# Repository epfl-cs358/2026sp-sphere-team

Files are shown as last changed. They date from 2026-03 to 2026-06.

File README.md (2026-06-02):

#  Sphere Robot

WhatsApp Image 2026-05-27 at 22 32 17

https://github.com/user-attachments/assets/e3d25818-d407-4145-80b4-8669d89c7ae2

A spherical robot inspired by BB-8. CS-358 final project, EPFL.

---

## Project Overview

It is a spherical robot inspired by BB-8 from Star Wars. A 3D-printed shell rolls on the ground, driven from the inside by a small chassis with three omnidirectional wheels. On top of the sphere, a separate "head" is held only by magnets, so it can rotate freely as the sphere moves. The head carries a camera.

The robot:

- Rolls in any direction using 3 omni wheels at 120° spacing, tilted inward at 30° against the inside of the sphere.
- Is driven over Wi-Fi from a browser dashboard.
- Streams live video from the head camera (planned — head firmware is in progress).
- Self-stabilizes with a 9-DOF IMU and a 100 Hz control loop.
- Can be reflashed over Wi-Fi (OTA), so the sphere doesn't have to be opened.

---

## Table of Contents

- [Bill of Materials](#bill-of-materials)
- [Build the Robot](#build-the-robot)
- [Algorithms](#algorithms)
- [Control Architecture](#control-architecture)
- [Communication Protocol](#communication-protocol)
- [Web App](#web-app)
- [Code — Repository Structure](#code--repository-structure)
- [Quick Start](#quick-start)
- [Make Commands](#make-commands)
- [Body Firmware (ESP32 C++)](#body-firmware-esp32-c)
- [Head Firmware](#head-firmware)
- [Webapp (Next.js — port 3003)](#webapp-nextjs--port-3003)
- [Stream Client + Relay (ports 3004/3005)](#stream-client-nextjs--port-3004--relay-port-3005)
- [System Requirements](#system-requirements)
- [WiFi Configuration](#wifi-configuration)

---

## Bill of Materials

### Electronic Components

| Component | Part | Notes | Link |
|---|---|---|---|
| Microcontroller (body) | ESP32 Wemos D1 R32 / UNO32 | Runs the control loop and the WebSocket server | Course provided |
| Camera (head) | XIAO Vision AI Camera (Seeed Studio) | Streams video from the head | [Digikey](https://www.digikey.ch/de/products/detail/seeed-technology-co-ltd/102010635/26553888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) |
| Motors (×3) | DFRobot FIT0186 | 12 V DC gear motors with encoders, one per omni wheel | [Bastel Garage](https://www.bastelgarage.ch/moteur-a-engrenages-dc-12v-251rpm-18kg-cm-avec-encodeur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) |
| Motor drivers (×3) | L298N H-bridge modules | One channel per motor | Course provided |
| IMU | Adafruit BNO055 | 9-DOF with built-in sensor fusion, I²C address 0x28 | [Bastel Garage](https://www.bastelgarage.ch/bno055-intelligent-9-axis-sensor) |
| Battery | LiPo | 5000mAh / 3S = 11V | Course provided |
| BMS | 3S 60A | Protects the LiPo | Course provided |
| Buck converter | LM2596 (or equivalent) | 12 V → 5 V for the ESP32 | Course provided |
| Servo | SG90 | Changes the angle of the camera | Course provided |
| Head Battery | Li-Ion Battery 3.7V 3200mA NCR18650B 18650 with Flat Top | Battery for servo and camera | [Bastel Garage](https://www.bastelgarage.ch/li-ion-battery-3-7v-3200ma-ncr18650b-18650-with-flat-top) |
| Head Battery shield | 1x18650 Lithium Battery Shield 5V 3A / 3V 1A | TO connect the head battery  | [Bastel Garage](https://www.bastelgarage.ch/1x18650-lithium-battery-shield-5v-3a-3v-1a) |

### Mechanical Parts (Body)

| Part | Material | Notes | File |
|---|---|---| --- |
| Omni wheels (×3), ~9.25 cm diameter | PETG/TPU  (3D printed) | | [Omniwheel](./README_files/Omniwheel) |
| Metal sticks (x15), 3mmx35mm | Steel (any metal can be used) |  Metals parts used to hold the omni wheels assembly |  |
| Motor Holder | PETG (3D printed) | One peice that holds the 3 motors at 120°, tilted inward by 30° | [Motor Holder](./README_files/Body/Motor%20holder.step) |
| Internal plates | MDF (laser-cut) | Structure for the electronical components | [Bottom](./README_files/Body/Internal%20Plate%20(Bottom).step) [Side for LiPo](./README_files/Body/Internal%20Plate%20(Side%20for%20LiPo).step) [Side](./README_files/Body/Internal%20Plate%20(Side).step) [Top](./README_files/Body/internal%20Plate%20(Top).step) |
| BMS Box | PETG (3D printed)  |  | [BMS Box (Cage)](./README_files/Body/BMS%20Box%20(Cage).step) [BMS Box (Plate)](./README_files/Body/BMS%20Box%20(Plate).step) |
| Tube Holder | PETG (3D printed) | Holds the tube for the magnets | [Pipe Holder](./README_files/Body/Pipe%20Holder.step) |
| 2 metal pipes (1.5mm(external diamateter) x 60mm & 2.5mm(external diamateter) x 200mm)| Aluminium (any metal can be used) | Tubes to hold and adjust the magnet holder and upper ball bearing |  |
| Hose clamp | PETG (3D printed) | Made to hold the bard in the body and make the magnets height adjustable | [Hose Clamp](./README_files/Body/Hose%20Clamp.step) |
| Magnet Holder | PETG (3D printed) | Holds all 3 magnets at the correct place | [Magnet Holder](./README_files/Body/Magnet%20Holder.step) |
| Magnets (x6) | Neodymium | (Ø 20 mm, height 5 mm N42) ; hold the head onto the sphere | [Supermagnete](https://www.supermagnete.ch/fre/aimants-disques-neodyme/disque-magnetique-20mm-5mm_S-20-05-N)|
| Sphere shell, 35 cm diameter | PETG (3D printed) | Two hemispheres, joined with magnets and tape | [Hemisphere](./README_files/Body/Sphere%20Shell%20(Hemisphere).step) [Rail](./README_files/Body/Sphere%20Shell%20(Rail).step) |

### Mechanical Parts (Head)
| Part | Material | Notes | File |
|---|---|---| --- |
| Head-to-sphere contact | Metal ball-bearings in 3D-printed cages | Low-friction contact between head and sphere | [Head-to-Sphere-folder](./README_files/Head-to-sphere%20contact) |
| Balls (14mm diameter) | Stainless Steel | Balls used in the heads ball bearing | [123Roulement](https://www.123roulement.ch/accessoire/bille-aiguille/bille/ba-14-aisi304) |
| Head shell | PETG (3D printed) | Holds the camera and magnets | [Head Shell](./README_files/Head/Head%20Shell.step) |
| Servo Holder | PETG (3D printed) | Holds the servo for the camera | [Servo Holder](./README_files/Head/Servo_Holder.step) |
| Camera Holder | PETG (3D printed) |  | [Camera Holder](./README_files/Head/Camera_Holder.step) |
---
---

## Build the Robot

### Sphere Shell

The sphere is what the wheels push against, so it needs to be round, rigid, and smooth on the inside. Inner radius is ~17.5 cm (35 cm diameter), matching the `ROBOT_RADIUS` constant in the firmware.

1. 3D print the two hemispheres (top and bottom) in PETG on a large-format printer (e.g. Prusa XL).
2. Set the slicer with the PETG optimal profile for your printer, using:
- Perimeters: 4
- Infill: 15%
- Supports: Organic supports, enabled for overhangs above 60°
3. Sand the inside of each hemisphere until it feels smooth. This is what gives the wheels good grip.
4. Add and glue the 27 rails onto one hemisphere.
5. Only join the two hemispheres at the very end, once the chassis is in place inside.



### Internal Chassis

The chassis holds the three motors at 120° spacing, each tilted inward at 30° from vertical so the wheels press against the inside of the sphere.

1. 3D print the [Motor Holder](./README_files/Body/Motor%20holder.step)
2. Lazer cut the internal plates ( [Bottom](./README_files/Body/Internal%20Plate%20(Bottom).step) [Side for LiPo](./README_files/Body/Internal%20Plate%20(Side%20for%20LiPo).step) [Side](./README_files/Body/Internal%20Plate%20(Side).step) [Top](./README_files/Body/internal%20Plate%20(Top).step) )
3. Test-fit the three motors first — don't glue or screw anything down until they fit cleanly.
4. Glue the bottom plate to the motor holder.
5. Gule the walls of the plates and screw the top plate on the walls.
6. Screw the [Pipe Holder](./README_files/Body/Pipe%20Holder.step) at the center of the plate and glue the 20mm tube inside.
7. Add the [Hose Clamp](./README_files/Body/Hose%20Clamp.step) and the 15mm tube on top.
8. Make sure the Hose clamp is well fitted in the lower tube (it should be pressed down).
9. Place the [Magnet Holder](./README_files/Body/Magnet%20Holder.step) on the upper tube.
10. Glue a ball transfer unit to the top of the tube.
11. Add the magnets to the magnet holder (make sur they all point in the same direction)
12. You will be able to adjuste height of the magnet holder and ball transfer unit once you have the complete sphere.
13. 3D print and screw on the upper plate the [BMS Box (Cage)](./README_files/Body/BMS%20Box%20(Cage).step) and [BMS Box (Plate)](./README_files/Body/BMS%20Box%20(Plate).step).
14. Screw every body electronical component onto it (there are two drivers on the bottom plate and one on top).
15. Mount the motors.
16. Mount the IMU as far as possible from the head magnets, and as low as possible in the chassis. A low center of mass keeps the robot stable.
17. Do the wiring (follow the electronical diagram)
   




### Motors and Wheels

1. 3D Print every file in the [Omniwheel](./README_files/Omniwheel) folder. Note that the material that should be used is in the file name.
2. Follow the following steps : https://github.com/epfl-cs358/2026sp-sphere-team/issues/80
4. Check the rolling direction. Choose one motor to be the front of your robot :  Motor 0 is at the front, motor 1 back-right, motor 2 back-left. If a motor spins the wrong way, swap fwd/rev in `body-firmware/src/config/pins.h` rather than rewiring.

### Electronics Assembly

**Electronics schematics**



**Motor drivers (L298N)**

| Motor | ESP32 GPIO (forward) | ESP32 GPIO (reverse) |
|---|---|---|
| 0 (front) | 14 | 27 |
| 1 (back-right) | 16 | 17 |
| 2 (back-left) | 25 | 26 |

Jumper EN HIGH on all three L298N boards. Connect L298N GND to ESP32 GND.

**Encoders**

| Motor | Encoder A | Encoder B |
|---|---|---|
| 0 | 34 | 35 |
| 1 | 2 | 4 |
| 2 | 36 | 39 |

**IMU (BNO055)**

| BNO055 | ESP32 |
|---|---|
| VIN | 3.3 V |
| GND | GND |
| SDA | 21 |
| SCL | 22 |

I²C address: 0x28.

**Power wiring**

```
LiPo ──┬── BMS ──┬── 12 V ──── L298N supply (×3)
       │         │
       │         └── LM2596 ── 5 V ── ESP32
       │                            └── BNO055 + encoders (via ESP32 3.3 V)
       └── status LED
```


> Add bulk capacitance (≥ 1000 µF + 0.1 µF ceramic) on the 12 V rail near each L298N. Without it, the motors will brown out the ESP32 every time you accelerate.

### Head and Camera

The head houses the XIAO Vision AI Camera and its own battery. It joins the same Wi-Fi as the body but streams video separately.

1. 3D print the [Head Shell](./README_files/Head/Head%20Shell.step), the [Servo Holder](./README_files/Head/Servo_Holder.step) and the [Camera Holder](./README_files/Head/Camera_Holder.step).
2. Screw the servo on the Servo holder.
3. Attach the camera to the camera holder.
4. Place the camera holder on the Servo.
5. Wire the Servo to the camera chip (follow the electronics head schematics).
6. Add the entenna to the exterior face of the head and connect it to the camera chip.
7. Screw the servo holder in the head.
8. Screw the head battery shield in the head.



   
9. Print every component in the [Head-to-Sphere-folder](./README_files/Head-to-sphere%20contact).
10. Screw the Ball Transfer Unit (Support) on the Head-to-sphere contact.
11. Add the ball and tube on top.
12. Place the magnets. Watch out that they should all point to the opposite direction from the body magnets.
13. Screw the Head-to-sphere contact to the sphere once everything works properly.



---

## Algorithms

### Omni-Wheel Inverse Kinematics

Given a desired body velocity (vx, vy, ω), we compute each wheel's target speed using the geometry of a 120°-spaced, inward-tilted omni layout.

For a wheel at angle θᵢ from the front:

```
ωᵢ = (1 / (r · cos α)) · [ −sin(θᵢ)·vx − cos(θᵢ)·vy − R·ω ]
```

where `r` is the wheel radius, `R` is the distance from the chassis center to the wheel contact, and `α` is the wheel tilt.

Robot constants (from `RobotConstants.h`):

| Parameter | Value |
|---|---|
| Wheel radius `r` | 0.046225 m (9.245 cm diameter) |
| Robot radius `R` | 0.1745 m (center to wheel contact) |
| Tilt angle `α` | 30° |
| Max RPM | 251 (per-wheel saturation) |

For our layout (θ₀ = 0°, θ₁ = 120°, θ₂ = 240°):

```
           1            ┌  0     −1     −R  ┐   ┌ vx ┐
[ωᵢ] = ───────────  ·   │ −√3/2   1/2  −R   │ · │ vy │
       r · cos(α)       └  √3/2   1/2  −R   ┘   └  ω ┘
```

Quick sanity checks:
- Pure forward → motor 0 doesn't spin, motors 1 and 2 spin opposite ways. ✓
- Pure rotation → all three spin in the same direction at the same speed. ✓
- Flat layout (α = 0) → equations match the standard 3-omni textbook case. ✓

Full derivation: `code/body-firmware/docs/omni-kinematics-derivation.md`

### Per-Wheel PID

Each motor has its own PID loop tracking the target speed from the kinematics.

| Parameter | Value |
|---|---|
| Input | Target RPM from kinematics |
| Feedback | Actual RPM from encoder |
| Output | PWM duty cycle (−1.0 to +1.0) |
| Kp / Ki / Kd | 0.005 / 0.002 / 0.0005 |
| Integrator clamp | ±5.0 |
| Loop rate | 100 Hz |

Code: `code/body-firmware/src/control/PID.h`

### Tilt-Limit Controller

The motors are powerful enough that on hard acceleration the chassis can climb the inside of the sphere and flip over. To prevent this, a controller watches the IMU:

| State | Condition | Action |
|---|---|---|
| Active | tilt < 15° | Normal driving |
| Recovery | tilt 15–20° | Coast motors, ignore joystick, wait for gravity. Re-engages once tilt drops ~3° |
| Stopped | tilt > 20° | Brake all motors, reset PIDs |
| Hard cap | tilt > 30° | Brake immediately, regardless of mode |

> **Status**: designed (see `controller-discussion.md`) but not yet integrated. The current shipping controller is a simple pass-through (`PassthroughDrivetrainController`), which is fine on flat ground with a careful operator.

---

## Control Architecture

### How the Two ESP32 Cores Split the Work

- **Core 0** runs the WebSocket server. It receives `vx,vy,omega` text frames from the laptop and drops the latest one into a one-slot mailbox (old commands are overwritten, never queued).
- **Core 1** runs the 100 Hz control loop. It reads the latest command, reads the IMU, runs the kinematics and the PIDs, and updates the motors.

```
WebSocket frame → mailbox → control loop (100 Hz) → kinematics → 3 × PID → 3 × motor
```

### Safety Properties

- **Stale commands stop the robot.** If no fresh command arrives within 200 ms, motors ramp smoothly to zero. No jerk, no runaway.
- **Watchdog reboot.** If the control loop ever hangs, the ESP32 resets itself within 1 second.
- **Wi-Fi watchdog.** If Wi-Fi has been disconnected for more than 30 s, the ESP32 reboots to reconnect cleanly.
- **Safe OTA.** Flashing over Wi-Fi first stops accepting commands, so the ramp-to-zero takes effect before the firmware is overwritten.
- **Latest command wins.** A joystick command from a second ago is worse than no command, so we never queue — we always use the most recent frame.

---

## Communication Protocol

The laptop talks to the body ESP32 over WebSocket on the local Wi-Fi.

- The ESP32 is the server, listening on port 80.
- The webapp is the client.

### Command Format

Plain text, comma-separated:

```
"vx,vy,omega"
```

| Field | Unit | Meaning |
|---|---|---|
| `vx` | m/s | Forward (positive = forward) |
| `vy` | m/s | Strafe (positive = left) |
| `omega` | rad/s | Yaw rate (positive = counterclockwise from above) |

Extra fields at the end are ignored — that's how we'll add new fields later (e.g. `head_tilt`) without breaking older clients.

### Video Stream

The head camera streams video to a small relay server (`code/stream-client/relay.ts`) running on the laptop. The webapp subscribes to the relay to display the feed.

- Camera → `ws://<laptop-ip>:3005/?role=producer`
- Browser → `ws://<laptop-ip>:3005/`

The relay fans out every frame from the camera to every viewer.

---

## Web App

Capture d’écran 2026-05-28 à 00 06 26
Capture d’écran 2026-05-28 à 00 06 46
Capture d’écran 2026-05-28 à 00 06 36

What you can do from the dashboard:

- **Live camera feed** — real-time video from the head.
- **Camera status** — online / offline / reconnecting.
- **Manual control** — joystick or keyboard input.
- **Emergency stop** — immediately sends `0,0,0` and locks input until you resume.
- **Telemetry** — IMU pose, battery voltage, loop rate.

The webapp is a Next.js app on port 3003. The video relay is a small Node server on port 3005. The video viewer is another Next.js app on port 3004.

Before running it, set your Wi-Fi credentials in `code/body-firmware/src/config/wifi_credentials.h`.

---

## Code — Repository Structure

```
code/
├── body-firmware/          # ESP32 C++ firmware for the body (motors, IMU, teleop)
│   ├── src/
│   │   ├── config/         # Pin definitions, WiFi credentials, debug macros
│   │   ├── control/        # Custom PID controller
│   │   ├── drivetrain/     # Omni kinematics, OmniDrivetrain, RobotConstants
│   │   │   └── controller/ # PassthroughDrivetrainController
│   │   ├── imu/            # BNO055 driver (orientation, gyro, calibration)
│   │   ├── input/          # WebSocketCommandProducer, CommandFrameParser
│   │   ├── motor/          # L298N, FIT0186Motor drivers, encoders
│   │   │   ├── constants/  # FIT0186-specific motor constants
│   │   │   └── driver/     # L298NDriver, BTS7960Driver
│   │   └── util/           # Shared types (Vec3, Quat, Euler, MovingAverage…)
│   │       └── sync/       # CommandLatch (thread-safe command queue)
│   ├── test/               # PlatformIO unit tests (native + hardware)
│   │   ├── test_omni_kinematics/
│   │   ├── test_omni_drivetrain/
│   │   ├── test_pid/
│   │   ├── test_command_latch/
│   │   ├── test_command_frame_parser/
│   │   ├── test_bno055_imu/
│   │   ├── test_fit0186_motor/
│   │   ├── test_l298n_driver/
│   │   ├── test_passthrough_controller/
│   │   ├── test_moving_average/
│   │   └── stubs/          # Arduino stubs for native tests
│   ├── platformio.ini
│   └── LIBRARIES.md
├── head-firmware/          # ESP32 firmware for the head (camera/streaming)
│   └── src/config/
├── webapp/                 # Next.js control interface (port 3003)
│   └── src/
│       ├── app/            # Next.js pages (home, /video)
│       ├── components/     # React components (video-stream.tsx)
│       └── lib/video/      # VideoSource abstraction
├── stream-client/          # Next.js streaming client (port 3004)
│   ├── src/app/
│   └── relay.ts            # WebSocket relay server (port 3005)
├── Makefile                # Unified commands for the whole monorepo
├── package.json
└── pnpm-workspace.yaml
```

---

## Quick Start

Before starting up the robot, read the [Safety_Procedures.pdf](https://github.com/user-attachments/files/28337480/Safety_Procedures.pdf)

```bash
make setup   # Install all dependencies
make dev     # Start all services
```

Once running:
- Webapp control interface: [Webapp](http://localhost:3003)
- Stream client: [link](http://localhost:3004) 
- WebSerial: [link](http://bb8-robot.local:81/webserial)

---

## Make Commands

### Development

| Command | Description |
|---|---|
| `make dev` | Start all services (webapp + stream + relay) |
| `make dev-webapp` | Webapp only (port 3003) |
| `make dev-stream` | Stream client only (port 3004) |
| `make dev-relay` | Relay server only (port 3005) |
| `make dev-stop` | Stop all dev servers (ports 3003–3005) |

### Testing

| Command | Description |
|---|---|
| `make test` | Run all tests |
| `make test-firmware` | Native PlatformIO tests (no hardware required) |
| `make test-firmware-head` | PlatformIO tests on hardware |
| `make test-webapp` | Webapp Vitest suite |
| `make test-stream` | Stream client Vitest suite |

### Build & Flash

| Command | Description |
|---|---|
| `make build` | Build entire project |
| `make build-webapp` | Build the webapp |
| `make build-stream` | Build the stream client |
| `make build-firmware` | Compile firmware (no upload) |
| `make flash` | Compile and flash firmware to the robot |
| `make monitor` | Serial monitor (115200 baud) |

### Code Quality

| Command | Description |
|---|---|
| `make lint` | ESLint on both web projects |
| `make typecheck` | TypeScript type checking |

### Setup

| Command | Description |
|---|---|
| `make setup` | Full setup (prerequisites + web + firmware) |
| `make setup-prereqs` | Check/install system dependencies |
| `make setup-web` | Install pnpm dependencies |
| `make setup-firmware` | Install PlatformIO + firmware libraries |
| `make clean` | Remove all build artifacts |

---

## Body Firmware (ESP32 C++)

### Teleop Pipeline Architecture

```
WebSocket client ──text frame──▶ WebSocketCommandProducer (Core 0)
                                          │
                                          ▼
                                  CommandLatch (latest-wins)
                                          │
                                          ▼
                              controlTask @ 100 Hz (Core 1)
                                          │
                                          ▼
                          PassthroughDrivetrainController
                                          │
                                          ▼
                                   OmniDrivetrain
                                  (3× FIT0186Motor + PID)
```

Commands are received over WebSocket on Core 0, stored in a `CommandLatch` (latest-wins, thread-safe), and consumed by the control task running at 100 Hz on Core 1. This dual-core split prevents WebSocket handling from interfering with motor control timing.

### Command Format

Commands are sent as plain text over WebSocket:

```
"vx,vy,omega"
```

| Field | Unit | Description |
|---|---|---|
| `vx` | m/s | Forward velocity |
| `vy` | m/s | Lateral (left) velocity |
| `omega` | rad/s | Rotation rate |

Frame convention: X-forward, Y-left, Z-up (consistent with BNO055 in NDOF mode).

Example: `"0.5,0.0,0.3"` moves the robot forward at 0.5 m/s while rotating at 0.3 rad/s.

### Safety Features

- **Stale command ramp-to-zero**: if no command is received within 200 ms, motors ramp down to zero.
- **Task watchdog**: 1-second timeout on both the control task and WebSocket task.
- **WiFi auto-reboot**: if the robot has been offline for 30 seconds, it automatically reboots.
- **No authentication**: WebSocket runs on `ws://` port 80 — intended for use on a trusted local network only.

### 3-Wheel Omni Kinematics

`OmniKinematics` converts a body-frame velocity `(vx, vy, omega)` into target RPM for each of the 3 motors arranged at 120° intervals. If any motor exceeds `maxRPM`, all outputs are normalized proportionally.

| Parameter | Value |
|---|---|
| Wheel radius | 46.225 mm |
| Robot radius | 174.5 mm |
| Tilt angle | 30° |
| Max RPM | 251 RPM |
| Control period | 10 ms (100 Hz) |
| Stale window | 200 ms |

### PID Controller

Custom PID with:
- **Anti-windup** via integral clamping
- **Derivative on measurement** (not on error) to avoid setpoint-change spikes
- **Configurable deadband**
- Output range: `[-1.0, 1.0]`

Current parameters: `Kp=0.005`, `Ki=0.002`, `Kd=0.0005`

### IMU — BNO055

- Mode: NDOF (9-DOF sensor fusion)
- Outputs: orientation quaternion, Euler angles, gyroscope, linear acceleration, gravity vector, calibration status
- Calibration offsets are saved to and restored from NVS flash (`Preferences`)

### Pin Assignment

| Signal | ESP32 Pin |
|---|---|
| Motor 0 FWD | 14 |
| Motor 0 REV | 27 |
| Motor 1 FWD | 16 |
| Motor 1 REV | 17 |
| Motor 2 FWD | 25 |
| Motor 2 REV | 26 |
| Encoder 0 A/B | 34 / 35 |
| Encoder 1 A/B | 2 / 4 |
| Encoder 2 A/B | 36 / 39 |
| IMU SDA | 21 |
| IMU SCL | 22 |

### PlatformIO Environments

| Environment | Purpose |
|---|---|
| `robot` | USB flash — full teleop firmware |
| `robot_ota` | OTA flash over WiFi (ArduinoOTA) |
| `drivetrain_test` | Drivetrain test firmware with RPM display |
| `motor_test` | Motor + encoder test firmware |
| `wemos_d1_uno32` | Base environment (IMU only) |
| `native` | Unit tests on the host machine |

### OTA Updates

1. Copy `wifi_credentials.example.h` → `wifi_credentials.h` and fill in your SSID, password, and OTA password.
2. Export the OTA password: `export OTA_PASSWORD='your-password'`
3. Flash: `pio run -e robot_ota -t upload`
4. If mDNS resolution fails: `pio run -e robot_ota -t upload --upload-port=<robot-ip>`

> During an OTA update, the `WebSocketCommandProducer` is stopped before flash write — motors stop within the stale window (≤ 200 ms).

### Unit Tests

Tests are located in `body-firmware/test/` and cover:

- Omni kinematics (`test_omni_kinematics`, `test_omni_drivetrain`)
- PID controller (`test_pid`)
- Command synchronization (`test_command_latch`, `test_command_frame_parser`)
- Motor drivers (`test_l298n_driver`, `test_fit0186_motor`, `test_bts7960_driver`)
- Passthrough controller (`test_passthrough_controller`)
- Utilities (`test_moving_average`)
- IMU (`test_bno055_imu`)

Run native tests (no hardware needed):
```bash
pio test -e native
```

Run tests on hardware:
```bash
make test-firmware-head
```

### Firmware Libraries

| Library | Version | Role |
|---|---|---|
| Adafruit BNO055 | 1.6.4 | IMU driver |
| Adafruit Unified Sensor | 1.1.15 | Sensor abstraction layer |
| Adafruit BusIO | 1.17.4 | I2C/SPI communication |
| ESP32Encoder | 0.12.0 | Hardware quadrature encoder reading |
| WebSockets (links2004) | 2.7.3 | WebSocket server for command reception |
| ArduinoOTA | built-in | OTA firmware updates over WiFi |
| FreeRTOS | built-in | Dual-core task scheduling |
| FFF (meekrosoft) | latest | Mocking framework for unit tests |

---

## Head Firmware

The head firmware runs on a second ESP32 and handles camera capture and video streaming. It connects to the stream relay over WebSocket and continuously sends JPEG frames.

Configuration is located in `head-firmware/src/config/`.

---

## Webapp (Next.js — port 3003)

Web control and monitoring interface for BB-8.

**Available pages:**
- `/` — Home page with navigation to modules
- `/video` — Live video feed from the head camera

**Planned modules (in progress):**
- RC Control — real-time keyboard/gamepad teleoperation
- Autonomous mode
- Telemetry dashboard

**Stack:** Next.js 15, TypeScript, Tailwind CSS, Vitest

---

## Stream Client (Next.js — port 3004) + Relay (port 3005)

The streaming client consumes the video feed from the robot's head and makes it available in the webapp through a WebSocket relay server.

### Streaming Architecture

```
Camera (head ESP32)
        │
        ▼
  stream-client (WebSocket producer)
        │  ws://localhost:3005?role=producer
        ▼
     relay.ts (relay server, port 3005)
        │  ws://localhost:3005
        ▼
  webapp video-stream.tsx (consumer)
```

`relay.ts` operates in producer/consumer mode: producers send frames, and the relay broadcasts them to all connected consumers. This decouples the robot's streaming from the number of web clients.

---

## System Requirements

| Dependency | Minimum version | Notes |
|---|---|---|
| Node.js | 18 | Required for webapp and stream client |
| pnpm | latest | Workspace package manager |
| Python | 3.8 | Required for PlatformIO |
| PlatformIO CLI | latest | `pip install platformio` |
| USB access | — | CH340 serial adapter for initial flash |

The development machine and the robot must be on the same local network for teleoperation and OTA updates.

---

## WiFi Configuration

Before the first flash, create the credentials file (gitignored):

```bash
cp code/body-firmware/src/config/wifi_credentials.example.h \
   code/body-firmware/src/config/wifi_credentials.h
```

Then fill in your credentials:

```cpp
#define WIFI_SSID     "your-network"
#define WIFI_PASSWORD "your-password"
#define OTA_PASSWORD  "your-ota-password"
```

> `wifi_credentials.h` is listed in `.gitignore` and will never be committed.

## Team members

| Name | Email |
|---|---|
| Alessandro Lombardini | alessandro.lombardini@epfl.ch |
| Tristan Compain | tristan.compain@epfl.ch |
| Lucas Brunschwick | lucas.brunschwick@epfl.ch |
| Vincent du Fresne | vincent.dufresnevonhohenesche@epfl.ch |
| Alban Thèves | alban.theves@epfl.ch |

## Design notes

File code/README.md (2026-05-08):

# Sphere

Monorepo for the Sphere robotics project — ESP32 firmware, web control interface, and streaming client.

## Quick start

```sh
make setup    # install all dependencies
make dev      # start all services
```

## Make targets

| Target | Description |
|---|---|
| `make dev` | Start all services (webapp + stream + relay) |
| `make dev-webapp` | Webapp only (port 3003) |
| `make dev-stream` | Stream client only (port 3004) |
| `make dev-relay` | Relay server only (port 3005) |
| `make dev-stop` | Stop all dev servers (ports 3003-3005) |
| `make test` | Run all tests |
| `make test-firmware` | PlatformIO native tests |
| `make test-firmware-head` | PlatformIO tests on hardware |
| `make test-webapp` | Webapp vitest |
| `make test-stream` | Stream client vitest |
| `make build` | Build everything |
| `make build-webapp` | Build webapp |
| `make build-stream` | Build stream client |
| `make build-firmware` | Compile firmware (no upload) |
| `make lint` | ESLint both web projects |
| `make typecheck` | TypeScript type checking |
| `make flash` | Compile and upload firmware to board |
| `make monitor` | Serial monitor (115200 baud) |
| `make setup` | Full setup (prereqs + web + firmware) |
| `make setup-prereqs` | Check/install system dependencies |
| `make setup-web` | Install pnpm dependencies |
| `make setup-firmware` | Install PlatformIO + firmware libs |
| `make clean` | Remove build artifacts |

## Body firmware: teleop pipeline

Body firmware ships a teleop pipeline:

```
WebSocket client  ──text frame──▶  WebSocketCommandProducer (Core 0)
                                            │
                                            ▼
                                     CommandLatch  (latest-wins, length-1)
                                            │
                                            ▼
                                  controlTask @ 100 Hz (Core 1)
                                            │
                                            ▼
                                  PassthroughDrivetrainController
                                            │
                                            ▼
                                       OmniDrivetrain
```

- Wire format: text frame `"vx,vy,omega"` (m/s, m/s, rad/s). Trailing fields are ignored for forward-compat.
- Build env: `pio run -e robot` (USB flash) or `pio run -e robot_ota -t upload` (OTA).
- Safety: 200 ms staleness ramp-to-zero, 1 s task watchdog on control + WS tasks, WiFi-offline reboot at 30 s.
- Auth: none — plaintext `ws://` on port 80, intended for trusted-LAN operation only.

## OTA updates

The `[env:robot_ota]` PlatformIO env flashes the device over WiFi via ArduinoOTA. Setup:

1. Set `OTA_PASSWORD` in `body-firmware/src/config/wifi_credentials.h` (gitignored).
2. Export the same password in your shell: `export OTA_PASSWORD='your-password'`.
3. `pio run -e robot_ota -t upload` — uploads to `bb8-robot.local` (mDNS) by default.
4. If `.local` name resolution fails, override with `pio run -e robot_ota -t upload --upload-port=<robot-ip>`.

OTA `onStart` halts the producer task before flash is overwritten so motors ramp to zero via the staleness window.

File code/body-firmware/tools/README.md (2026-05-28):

# BB-8 tuning tools

`tune_pid.py` is a persistent telemetry capture daemon plus a set of LLM-safe inspection commands for tuning the balancing PID. The `tuning-pid-balance` Claude skill (`~/.claude/skills/tuning-pid-balance/SKILL.md`) drives this tool.

## Quick start (foreground)

Install deps once, then run the daemon in the background:

```
pip install -r tools/requirements.txt
nohup python3 tools/tune_pid.py capture --host bb8.local > /tmp/cap.log 2>&1 &
```

Capture writes to `~/.bb8-telemetry/sessions/<id>/` and updates the `~/.bb8-telemetry/current` symlink. Ctrl-C / `kill` flushes cleanly. Re-launching starts a new session.

## Quick start (launchd)

Persistent across reboots and login sessions. Edit `tools/com.bb8.tune-capture.plist` and replace `<USERNAME>` with your macOS username and `<HOST>` with the robot's mDNS name (default `bb8.local`), then:

```
cp tools/com.bb8.tune-capture.plist ~/Library/LaunchAgents/com.bb8.tune-capture.plist
launchctl load   ~/Library/LaunchAgents/com.bb8.tune-capture.plist
launchctl list | grep com.bb8.tune-capture          # verify
```

Logs land in `/tmp/bb8-tune-capture.{out,err}.log`. To stop:

```
launchctl unload ~/Library/LaunchAgents/com.bb8.tune-capture.plist
```

## Install the tuning skill

The skill is already in place at `~/.claude/skills/tuning-pid-balance/SKILL.md`. Invoke from any Claude session via `/tuning-pid-balance`.

## Inspection commands cheat sheet

All subcommands operate on `--session current` by default. Output is bounded JSON — safe to pipe into Claude via Bash.

| Command | Purpose |
|---|---|
| `tune_pid.py sessions` | List sessions with start time, end time, and row count. |
| `tune_pid.py manifest` | Print the active session's manifest (gain + arming history, fault count, seq gaps). |
| `tune_pid.py summary --window 10s` | Default read. Constant-size JSON: per-axis min/max/mean/std, event counts, saturation %, oscillation period if any. |
| `tune_pid.py events --window 30s` | Decoded event rows (`event_flags != 0`) only. Capped at 200 rows. |
| `tune_pid.py slice --around <seq> --max-rows 200 --columns ...` | Narrow window around an event, downsampled, named columns only. |
| `tune_pid.py oscillation --axis pitch --window 10s` | Autocorrelation period + amplitude. Used to derive Tu in Ziegler-Nichols. |
| `tune_pid.py plot --window 30s --out /tmp/last.png` | Six-panel PNG with event markers. Read via Claude's multimodal image input. |

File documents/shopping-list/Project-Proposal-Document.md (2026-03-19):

# Project Proposal — BB8 Robot with Omni Wheels

## 1. High-level project description

## 2. Related projects & resources

Project 1 — 

Project 2 —

...

## 3. User stories

## 4. Product management & afterlif

Follow-up projects for future CS-358 students:

Autonomous navigation (SLAM, obstacle avoidance)
Face tracking via the onboard camera
Embedded voice interface
Gesture recognition for hand-based control

Real, non-EPFL users

Interactive guide
Social companion
Retail environments

Startup opportunity
[Briefly describe the concept: modular robotics platform, SaaS model for behaviors/content, target markets.]

## 5. Shopping List

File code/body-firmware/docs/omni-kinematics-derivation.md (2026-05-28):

# Omni-Wheel Inverse Kinematics Derivation

## Setup

A 3-omniwheel drivetrain inside a spherical shell. Wheels are equally spaced at 120° and tilted inward at angle α from vertical to contact the sphere's inner surface.

### Coordinate Frame (body-frame, right-handed)

- **x**: forward (direction the robot faces)
- **y**: left
- **z**: up

All velocities are in the body frame. Positive omega = counter-clockwise when viewed from above (right-hand rule around z-up).

This matches the BNO055 IMU's default coordinate frame, so no axis remapping is needed.

### Wheel Positions (viewed from above, CCW from body +x)

Angles are measured **counter-clockwise from the body +x axis (forward)** when viewed from above, matching `DrivetrainConfig::wheelAngles` consumed by `OmniKinematics`.

| Motor | Angle θ (CCW from +x) | Physical position |
|---|---|---|
| 0 | 180° | Back |
| 1 | 300° | Front-right |
| 2 |  60° | Front-left |

Each wheel's axis of rotation points toward the center of the robot. The wheel rolls in the direction perpendicular to its axis.

Source of truth for motor index ↔ physical position: `src/main_motor_test.cpp:5-7` and `RobotConstants.h:29`.

### Parameters

| Symbol | Meaning |
|---|---|
| r | Wheel radius (m) |
| R | Robot radius — distance from center to wheel contact point (m) |
| α | Tilt angle from vertical (rad) |
| vx | Forward body velocity (m/s), positive = forward |
| vy | Strafe body velocity (m/s), positive = left |
| ω | Rotation rate (rad/s), positive = CCW from above |

### Tilt correction assumption

The `1/cos(α)` factor assumes the wheel radius `r` already accounts for the sphere contact geometry — i.e., `r` is the effective wheel radius at the contact point, not necessarily the physical wheel radius. This is a valid first-order approximation. If the exact sphere contact geometry differs, `r` should be adjusted accordingly.

## Derivation

### Step 1: Flat-floor 3-omniwheel IK

For a wheel at angle θ_i (measured CCW from body +x when viewed from above), its contact point sits at position `R × (cos θ_i, sin θ_i)`. The wheel's rolling direction is perpendicular to that radial vector, tangent to the circle. We pick the tangent `(-sin θ_i, cos θ_i)` so that positive wheel angular velocity drives the body CCW (matching `+ω = CCW from above`).

The velocity at the wheel contact point has two parts:
1. **Translation**: the robot's linear velocity (vx, vy)
2. **Rotation**: tangential velocity from the body spinning at ω = `R × ω` along the same tangent direction

Projecting the contact-point velocity onto the rolling direction `(-sin θ_i, cos θ_i)`:

```
v_wheel_i = -sin(θ_i) × vx + cos(θ_i) × vy + R × ω
```

The `-sin(θ_i) × vx + cos(θ_i) × vy` term projects the linear velocity onto the rolling direction. The `+R × ω` term adds the rotational contribution: positive ω (CCW) makes all wheels spin in the same positive direction. This matches `OmniKinematics::toWheelRPMs` in `src/drivetrain/OmniKinematics.h:30`.

The wheel angular velocity is:

```
ω_i = v_wheel_i / r
```

### Step 2: Tilt correction

When wheels are tilted at angle α from vertical, the effective radius of contact with the sphere changes. The wheel's force is projected onto the horizontal plane by a factor of cos(α). This means the wheel must spin faster to achieve the same horizontal velocity:

```
ω_i = v_wheel_i / (r × cos(α))
```

At α = 0 (vertical wheels, flat floor), cos(0) = 1 and this reduces to the standard equation. As α → 90° (wheels horizontal), cos(α) → 0 and the required wheel speed → ∞, which is the physical limit where the wheels can no longer drive the sphere.

### Step 3: Full equations

Combining steps 1 and 2:

```
ω_i = (1 / (r × cos(α))) × [-sin(θ_i) × vx + cos(θ_i) × vy + R × ω]
```

### Step 4: Expand per wheel

Using CCW angles θ₀ = 180°, θ₁ = 300°, θ₂ = 60°:

**Motor 0 (back, θ = 180°):**
```
sin(180°) = 0,  cos(180°) = -1

ω₀ = (1 / (r × cos(α))) × [-0 × vx + (-1) × vy + R × ω]
ω₀ = (1 / (r × cos(α))) × [-vy + R × ω]
```

**Motor 1 (front-right, θ = 300°):**
```
sin(300°) = -√3/2 ≈ -0.866,  cos(300°) = 1/2 = 0.5

ω₁ = (1 / (r × cos(α))) × [-(-0.866) × vx + 0.5 × vy + R × ω]
ω₁ = (1 / (r × cos(α))) × [0.866 × vx + 0.5 × vy + R × ω]
```

**Motor 2 (front-left, θ = 60°):**
```
sin(60°) = √3/2 ≈ 0.866,  cos(60°) = 1/2 = 0.5

ω₂ = (1 / (r × cos(α))) × [-0.866 × vx + 0.5 × vy + R × ω]
```

### Step 5: Matrix form

```
┌ ω₀ ┐         1          ┌  0     -1    R ┐   ┌ vx ┐
│ ω₁ │ = ───────────── ×  │  √3/2   1/2  R │ × │ vy │
└ ω₂ ┘   r × cos(α)       └ -√3/2   1/2  R ┘   └ ω  ┘
```

### Step 6: Convert to RPM

```
RPM_i = ω_i × 60 / (2π)
```

## Sanity Checks

### Pure forward (vx > 0, vy = 0, ω = 0)

```
ω₀ = 0                            ← motor 0 (back) is still
ω₁ = +0.866 × vx / (r × cos(α))  ← positive (front-right)
ω₂ = -0.866 × vx / (r × cos(α))  ← negative (front-left)
```

The two front wheels (motors 1, 2) spin at equal magnitude, opposite directions. Forward motion comes from their combined horizontal thrust. Motor 0 (back) contributes nothing — its rolling axis is purely lateral, so it cannot push the shell forward. ✓

### Pure strafe left (vx = 0, vy > 0, ω = 0)

```
ω₀ = -vy / (r × cos(α))          ← negative (back wheel spins one way)
ω₁ = +0.5 × vy / (r × cos(α))   ← positive (front-right)
ω₂ = +0.5 × vy / (r × cos(α))   ← positive (front-left, same as motor 1)
```

Motor 0 (back) takes a single full-magnitude contribution in the negative direction; motors 1 and 2 (front pair) each take half-magnitude in the positive direction. The three contributions sum to net leftward thrust on the shell, matching the `+y = LEFT` REP-103 convention. ✓

### Pure CCW rotation (vx = 0, vy = 0, ω > 0)

```
ω₀ = +R × ω / (r × cos(α))
ω₁ = +R × ω / (r × cos(α))
ω₂ = +R × ω / (r × cos(α))
```

All three motors spin at equal speed in the same positive direction, driving the body CCW from above. ✓

### Tilt angle = 0

All equations reduce to standard flat-floor IK (cos(0) = 1). ✓

## References

- [ROS2 Mobile Robot Kinematics — Omnidirectional Wheels](https://control.ros.org/rolling/doc/ros2_controllers/doc/mobile_robot_kinematics.html)
- [Modern Robotics Ch. 13.2 — Omnidirectional Wheeled Mobile Robots](https://modernrobotics.northwestern.edu/nu-gm-book-resource/13-2-omnidirectional-wheeled-mobile-robots-part-1-of-2/)
- Borisov et al., "Nonholonomic dynamics and control of a spherical robot with an internal omniwheel platform" (2016)
- SpheriDrive: A spherical robot with an innovative 3-wheeled platform (2025)

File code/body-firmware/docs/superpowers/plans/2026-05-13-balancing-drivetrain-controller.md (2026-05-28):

# BalancingDrivetrainController Implementation Plan

**Spec:** `code/body-firmware/docs/superpowers/specs/2026-05-13-balancing-drivetrain-controller-design.md`
**PR shape:** one PR, two logical phases. Each phase ends with a reviewer-subagent pass.
**Final-resting plan path (post-approval):** copy this file to `code/body-firmware/docs/superpowers/plans/2026-05-13-balancing-drivetrain-controller.md`. Plan-mode only allows writing to `~/.claude/plans/`.

---

## Context

The robot today routes joystick `BodyVelocity` straight to `OmniDrivetrain` via `PassthroughDrivetrainController` — no IMU feedback, no balancing, no operator arm/disarm. The spec turns the platform into a Segway-style balancer: tilt is the inner loop, IMU drives feedback, and an explicit `ArmingState` (DISARMED / ARMED / KILLED) gates the controller. OTA flashes disarm automatically. Tuning happens live over RemoteSerial with NVS persistence.

The reviewer found a clean seam: the wire-protocol / safety scaffolding ships independently of the balancing controller. Phase 1 lands that scaffolding as a no-op (`PassthroughDrivetrainController` stays wired, system boots DISARMED). Phase 2 lands the balancing controller + tuner + bench harness and swaps the wire-in. Both phases live in one PR so the wire format and the controller that consumes it can't drift.

## Pre-flight assumptions (resolved during STEP 0)

| Question | Decision | Rationale |
| --- | --- | --- |
| Where does `OtaSafeMode::onStart() → ArmingState::disarm()` live? | Inline call inside the existing `ArduinoOTA.onStart` lambda at `OtaSafeMode.cpp:112-115`. | Spec's plain reading; minimal change. Creates `network/ → safety/` include dep (acceptable). |
| Keep `OtaSafeMode::isUpdating()` hot-path check in control task? | Remove the check, keep the API. | Per spec §"OTA composition": arming-state alone provides the guarantee. API stays for status read-back. |
| How to express the tagged Velocity-or-Control parser result? | Extend `FrameParseResult` with a `FrameKind kind` and `ControlVerb control` field. | No `std::variant` precedent in this codebase; one struct stays cheap and easy to read. |
| `RemoteSerial` per-verb registration? | None — `RemoteSerial::onMessage()` is a *single* callback. `main_balance_test.cpp` and `main_robot.cpp` each install one dispatcher that calls `ArmingHandlers::handle(line)` and falls through to `BalanceTuner::handle(line)`. | Matches existing `main_drivetrain_test.cpp` pattern. No new infra. |
| BNO055 axis-remap currently applied? | No. Gyro reads pass through raw. The spec's `gyroPitchSign` / `gyroRollSign` knobs in `BalanceConfig` are the empirical sign-flip lever; bench tuning procedure documents the verification. | Spec already handles this — no plan adjustment needed. |
| `BalanceConfig` factory location? | `RobotConstants::balanceConfig()` in existing `src/drivetrain/RobotConstants.h`. | File already has `drivetrainConfig()`; matches the pattern. |

## Multi-agent workflow

The plan executes in four wave-types per phase: **research → parallel impl → sequential integration → verification**. Implementation agents should not need to make judgment calls — every prompt includes exact files, function signatures, test cases, and verify commands. Anything ambiguous is resolved up-front in research, not by the impl agent.

### Wave 0 — research (already complete)

Performed before this plan was written, in STEP 0 of the planning task. The "Pre-flight assumptions" table at the top of this file records the decisions. No further research wave is required before execution. If, mid-execution, an impl agent reports back "I had to guess about X," the orchestrator dispatches a one-off Explore agent for X and updates the affected step before the next wave.

### Subagent prompt template (use verbatim per step; substitute placeholders)

```
You are implementing Step <N.M> of the BalancingDrivetrainController plan.

Plan file: /Users/alessandro/.claude/plans/task-write-the-fuzzy-octopus.md
Spec:      code/body-firmware/docs/superpowers/specs/2026-05-13-balancing-
           drivetrain-controller-design.md

Read Step <N.M> in full. It is self-contained — it lists every file to
touch, every test case to write, and the commit message. Do not invent
behaviour or refactor beyond the step's scope. If a fact in the step
disagrees with what you find on disk, stop and report — do not improvise.

Workflow (strict TDD):
  1. Create / extend the test file(s) named in "Tests first". Use exactly
     the test names and assertions given.
  2. Run the verify command from "Done when" (typically
     `pio test -e native -f <suite>`). Confirm tests fail with the expected
     error (compile-fail or assertion-fail). Capture the output.
  3. Create / modify the implementation files named in "Implementation"
     using exactly the signatures and code shapes given.
  4. Re-run the verify command. Confirm all listed tests pass. Capture
     the output.
  5. Stage ONLY the files listed in the step's "Commit" block. Never
     `git add -A` / `git add .` — other agents may have unrelated work
     in this worktree.
  6. Commit with the exact subject from the step. No body unless the step
     says otherwise. No `Co-Authored-By`. No testing summaries.

Hard constraints:
- Do not touch files outside the step's stage-list. Surface anything else
  you notice in your report instead of fixing it.
- Do not skip the failing-tests-first step. The orchestrator will reject
  reports that don't include the red→green transition.
- Do not rebase, force-push, or rewrite history.

Report back (under 200 words):
- Commit SHA produced
- The exact verify command(s) you ran + truncated pass/fail output
- Any step text that disagreed with the current code (do not act on the
  disagreement; surface it)
```

### Wave 1 — parallel implementation (research-free, leaf nodes)

Steps with no dependencies on other steps fan out together in one `Agent` message. The orchestrator sends N `Agent` tool-use blocks in a single response, then waits for all N reports before applying their commits.

| Wave | Steps (parallel) | Predicate |
| --- | --- | --- |
| Phase 1 — Wave 1 | **1.1** PID 4-arg overload · **1.2** ArmingState · **1.3** Parser sigil dispatch | none |
| Phase 2 — Wave 1 | **2.1** Controller `dt` param · **2.2** BalanceConfig + factory · **2.3** quatToBodyGravity utility | Phase 1 complete |

Three parallel agents per phase. Each agent owns one focused TDD unit. Build verify: `pio test -e native` (each agent runs its own focused `-f <suite>` subset).

### Wave 2 — sequential integration (wires the leaves together)

Steps that depend on Wave-1 outputs. Run inside-out: leaves of the dep DAG first, root last.

| Wave | Steps | Depends on |
| --- | --- | --- |
| Phase 1 — Wave 2a | **1.4** WS control-frame dispatch · **1.5** OTA → disarm hook | 1.2, 1.3 / 1.2 (parallel within 2a) |
| Phase 1 — Wave 2b | **1.6** `main_robot` arming gate | 1.2, 1.4, 1.5 |
| Phase 2 — Wave 2a | **2.4** BalancingDrivetrainController · **2.5** NVS persistence | 1.1, 2.1, 2.2, 2.3 / 2.2 (parallel within 2a) |
| Phase 2 — Wave 2b | **2.6** BalanceTuner | 1.2, 2.2, 2.5 |
| Phase 2 — Wave 2c | **2.7** bench harness · **2.8** `main_robot` swap · **2.9** runbook | 2.4, 2.6 (all three parallel) |

Wave 2a is parallel within itself; Wave 2b and 2c block on the wave before them. Verify per step.

### Wave 3 — verification (review + build + hardware)

| Phase | Step | Type | Action |
| --- | --- | --- | --- |
| Phase 1 — end | **1.7** reviewer subagent | software | Dispatch general-purpose agent with the Phase-1 reviewer prompt from Step 1.7. Block on its report. Fix any flagged blockers as fixup commits before starting Phase 2. |
| Phase 2 — end | **2.10** final reviewer subagent | software | Dispatch general-purpose agent with the full-PR reviewer prompt from Step 2.10. Block on its report. Fix any blockers before opening the PR. |
| Phase 2 — end | (operator) bench checklist | hardware | The human runs the checklist from the runbook (`docs/superpowers/runbooks/2026-05-13-balance-bringup.md`) on the actual robot. No agent can do this. Open the PR only after the bench checklist passes. |

The reviewer agents do **not** modify code. They audit a frozen diff. Their output is a findings table; the orchestrator decides which findings warrant fixup commits.

### Orchestrator pseudocode

```python
# Phase 1
for agent in parallel([dispatch(step) for step in [1.1, 1.2, 1.3]]):
    apply(agent.commit)
for agent in parallel([dispatch(step) for step in [1.4, 1.5]]):
    apply(agent.commit)
apply(dispatch(1.6).commit)
review_report = dispatch(1.7)
apply_fixups_if_any(review_report)

# Phase 2
for agent in parallel([dispatch(step) for step in [2.1, 2.2, 2.3]]):
    apply(agent.commit)
for agent in parallel([dispatch(step) for step in [2.4, 2.5]]):
    apply(agent.commit)
apply(dispatch(2.6).commit)
for agent in parallel([dispatch(step) for step in [2.7, 2.8, 2.9]]):
    apply(agent.commit)
review_report = dispatch(2.10)
apply_fixups_if_any(review_report)

# Hardware (operator-driven, not agentic)
run_bench_checklist()
open_pr()
```

## Conventions (apply to every commit)

- One atomic commit per step. Imperative subject. No body unless a non-obvious tradeoff needs documenting.
- **Never `git add -A` / `git add .`.** Stage only the files this step touches.
- No `Co-Authored-By` trailer. No testing summaries in commit messages or PR body.
- Tests first, run them, see them fail, write implementation, run again, see them pass. Then commit.
- After any C/C++ change: `pio test -e native` must pass before commit. PlatformIO compile check for the affected env (`robot`, `balance_test`) runs at the end of each phase.

---

# Phase 1 — Foundations & Safety (no behavioural change to drivers)

End-state of Phase 1: the robot still uses `PassthroughDrivetrainController`. `ArmingState` exists and gates the control task. Boot default is `DISARMED` so the robot won't move until the operator sends `c:arm` over the new wire format. OTA flashes disarm automatically.

---

### Step 1.1 — `PID` 4-arg overload (rate-aware)

**Inputs:** `src/control/PID.h`, `test/test_pid/test_pid.cpp`, spec §"PID extension".

**Tests first** (append to `test/test_pid/test_pid.cpp`):
- `test_4arg_with_finite_diff_rate_matches_3arg` — call 3-arg `compute(s, m, dt)` on one PID; call 4-arg `compute(s, m, (m - m_prev)/dt, dt)` on a fresh PID after the same warm-up call; assert equal output within `TOL`.
- `test_4arg_with_external_rate_uses_supplied_rate` — set `Kd = 1.0`, `Kp = Ki = 0`. First call seeds state. Second call: `compute(setpoint=0, measurement=0, rate=2.0, dt=0.1)`; assert output ≈ `-2.0` (derivative-on-measurement: `-Kd * rate`). Independent of `_prevMeasurement`.
- `test_4arg_respects_anti_windup` — `Ki = 1.0`, output clamped `[-1, +1]`. Drive 4-arg version with large positive error 10 times; assert integral does not exceed `_outputMax / _ki`.
- `test_4arg_respects_deadband` — `deadband > 0`, setpoint=0, measurement < deadband, rate=0; assert returns 0 and resets state.
- Register all four in `main()` `RUN_TEST` block.

Run: `pio test -e native -f test_pid` — expect 4 new failures.

**Implementation** (`src/control/PID.h`):
- Add `float compute(float setpoint, float measurement, float rate, float dt)` containing the canonical body. The current 3-arg `compute` becomes a thin wrapper:
  ```cpp
  float compute(float setpoint, float measurement, float dt) {
      float rate = _firstCompute ? 0.0f : (measurement - _prevMeasurement) / dt;
      return compute(setpoint, measurement, rate, dt);
  }
  ```
- The 4-arg version uses `derivative = -rate` (derivative-on-measurement, same sign as today).
- 4-arg version still updates `_prevMeasurement` so a later 3-arg call sees the right history (gives consumers freedom to mix).
- File stays header-only.

Run: `pio test -e native -f test_pid` — expect all green (old + new).

**Parallel?** Yes. No dependencies on other Phase-1 work.

**Done when:** All `test_pid` cases pass; spot-check that `OmniDrivetrain`'s per-wheel PID calls still compile (they continue using the 3-arg form).

**Commit:** `pid: add rate-aware 4-arg compute() overload`

Files staged: `src/control/PID.h`, `test/test_pid/test_pid.cpp`.

---

### Step 1.2 — `ArmingState` module

**Inputs:** Spec §"ArmingState", existing `src/util/` for header conventions (e.g. `BB8_ASSERT` patterns).

**Tests first** — new dir `test/test_arming_state/test_arming_state.cpp`. Mirror the spec test table verbatim:
- `test_boot_state_is_disarmed` — after `ArmingState::begin()`, `get() == Disarmed`; `isArmed() == false`.
- `test_disarmed_to_armed` — `arm()` → `get() == Armed`; `isArmed() == true`.
- `test_armed_to_disarmed` — from Armed, `disarm()` → `get() == Disarmed`.
- `test_any_to_killed` — from Armed: `kill()` → `Killed`. Fresh state, from Disarmed: `kill()` → `Killed`.
- `test_arm_while_killed_is_noop` — `kill(); arm();` → still Killed.
- `test_clearkill_from_non_killed_is_noop` — from Disarmed: `clearKill();` → still Disarmed; from Armed: `clearKill();` → still Armed.
- `test_clearkill_from_killed_to_disarmed` — `kill(); clearKill();` → Disarmed.

Helper at top of file resets state between tests by calling `begin()` in `setUp()`.

Run: `pio test -e native -f test_arming_state` — expect compile failure (header doesn't exist).

**Implementation:**
- Create `src/safety/ArmingState.h` exposing the namespace API exactly as in the spec (lines 117-130). Add `-Isrc/safety` to `platformio.ini` includes for `env:native`, `env:robot`, `env:wemos_d1_uno32`, `env:wemos_d1_uno32_ota_console` (one line each).
- Create `src/safety/ArmingState.cpp` with `std::atomic<State> g_state{State::Disarmed}` (file-static). `arm()` / `disarm()` use `compare_exchange_strong` only if Killed-aware semantics need it; per spec a plain `if (get() == Killed) return; g_state.store(...)` is sufficient given the single-writer invariant — document the invariant in a one-line comment at the top of the .cpp.
- Each transition logs to both `Serial` and `RemoteSerial::println(...)`. Guard the `RemoteSerial::println` with a `#ifdef ARDUINO` since native tests don't link `RemoteSerial`. Equivalent: put the log calls behind a thin `arming_log(const char*)` static that no-ops on native builds.
- Update `env:native` build_flags: add `-Isrc/safety`. Update `src/network/`-adjacent envs likewise.

Run: `pio test -e native -f test_arming_state` — expect green.

**Parallel?** Yes. No dependencies.

**Done when:** all 7 arming-state tests pass; `pio run -e robot` still compiles (sanity check for include path).

**Commit:** `safety: add ArmingState (Disarmed/Armed/Killed) module`

Files staged: `src/safety/ArmingState.h`, `src/safety/ArmingState.cpp`, `test/test_arming_state/test_arming_state.cpp`, `platformio.ini`.

---

### Step 1.3 — `CommandFrameParser` sigil dispatch + tagged result

**Inputs:** `src/input/CommandFrameParser.h`, `test/test_command_frame_parser/` (existing layout for fixture style), spec §"Wire protocol".

**Tests first** (append to existing `test/test_command_frame_parser/test_command_frame_parser.cpp`):
- `test_legacy_velocity_unprefixed_still_parses` — input `"1.0,2.0,3.0"` → `kind == Velocity`, `velocity == {1, 2, 3}`, `error == None`.
- `test_velocity_with_v_sigil_parses` — input `"v1.0,2.0,3.0"` → same as above.
- `test_control_arm` — input `"c:arm"` → `kind == Control`, `control == ControlVerb::Arm`.
- `test_control_disarm` — input `"c:disarm"` → `control == ControlVerb::Disarm`.
- `test_control_kill` — input `"c:kill"` → `control == ControlVerb::Kill`.
- `test_control_clearkill` — input `"c:clearkill"` → `control == ControlVerb::ClearKill`.
- `test_control_unknown_verb` — input `"c:explode"` → `error == InvalidControlVerb` (new enum member).
- `test_control_missing_colon` — input `"carm"` → `error == InvalidControlVerb` (or new `MalformedControlFrame`; pick one and use it consistently).
- `test_negative_leading_minus_is_velocity` — input `"-1.0,0,0"` → velocity-path (regression — the sigil dispatcher must treat `-`, `+`, digit, `.` as velocity-like).

Run: `pio test -e native -f test_command_frame_parser` — expect compile failure / failures.

**Implementation:**
- Edit `src/input/CommandFrameParser.h`. Add new enums and fields:
  ```cpp
  enum class FrameKind : uint8_t { Velocity, Control };
  enum class ControlVerb : uint8_t { Arm, Disarm, Kill, ClearKill };
  // Extend FrameParseError with InvalidControlVerb.
  struct FrameParseResult {
      FrameKind kind = FrameKind::Velocity;
      BodyVelocity velocity{};
      ControlVerb  control = ControlVerb::Arm;
      FrameParseError error = FrameParseError::None;
      bool ok() const { return error == FrameParseError::None; }
  };
  ```
  Rename the existing `value` field to `velocity` (4 call sites under `WebSocketCommandProducer.cpp:148-161` need the rename — bundle that into the same commit so the rename never lands half-applied).
- In `parseCommandFrame`, after the length check, inspect `buf[0]`:
  - `'c'` → control path: require `buf[1] == ':'`, then `strcmp` (or `memcmp` against fixed-length strings) for the four verbs. Return early.
  - `'v'` → velocity path: advance `p` past the `'v'`, then existing CSV logic.
  - digit / `'-'` / `'+'` / `'.'` → velocity path, existing CSV logic from start.
  - anything else → `InvalidVx` (current behaviour for malformed leading char).
- Keep all existing velocity-parse failure modes unchanged.

Run: `pio test -e native -f test_command_frame_parser` — expect green (old + new).

**Parallel?** Yes. Independent of 1.1 and 1.2.

**Done when:** all parser tests pass; backward-compat regression test (unprefixed velocity) passes.

**Commit:** `parser: extend CommandFrameParser with sigil dispatch (v/c)`

Files staged: `src/input/CommandFrameParser.h`, `src/input/WebSocketCommandProducer.cpp` (field-rename only), `test/test_command_frame_parser/test_command_frame_parser.cpp`.

---

### Step 1.4 — `WebSocketCommandProducer` control-frame dispatch

**Inputs:** Steps 1.2, 1.3. Files: `src/input/WebSocketCommandProducer.cpp`, `test/test_mock_command_producer/` (existing fixture style).

**Tests first** — new file `test/test_websocket_control_dispatch/test_websocket_control_dispatch.cpp`. Use FFF fakes for `ArmingState`:
- `DECLARE_FAKE_VOID_FUNC(ArmingState_arm); DECLARE_FAKE_VOID_FUNC(ArmingState_disarm); ...` etc, with a tiny shim header that redefines the namespace functions for the test binary only. (Pattern: see how `test_mock_command_producer` handles transport stubs.)
- `test_control_arm_frame_invokes_arming_state_arm` — feed parser result `{kind=Control, control=Arm}` to the dispatcher; assert `ArmingState_arm_fake.call_count == 1`, latch.write was NOT called.
- `test_control_disarm` / `test_control_kill` / `test_control_clearkill` — analogous.
- `test_velocity_frame_writes_latch_does_not_invoke_arming` — feed velocity frame; assert latch.write count == 1, no arming calls.

Run: expect compile failure (`dispatch()` helper doesn't exist).

**Implementation:**
- Note the file's current shape (post-commit 8a28fc1): `WStype_CONNECTED` uses `_activeClient.exchange(clientNum)` for drop-oldest pre-emption, and heartbeat is `enableHeartbeat(3000, 2500, 2)`. **Do not touch either** — they are orthogonal to this step. Only the `WStype_TEXT` branch (currently lines ~146-174) is in scope.
- Extract the `WStype_TEXT` body into a static-or-private member `void dispatchFrame(const FrameParseResult& r)` that:
  - On `r.kind == FrameKind::Velocity`: `_latch.write(r.velocity)`, increment `_frameCount`.
  - On `r.kind == FrameKind::Control`: switch on `r.control` calling `ArmingState::arm() / disarm() / kill() / clearKill()`. Log each transition to `Serial.printf("[ws] control: %s\n", verbName)`.
- The original event handler calls `dispatchFrame(result)` after the `ok()` check.
- Include `safety/ArmingState.h` in `WebSocketCommandProducer.cpp`.
- The control-frame path does not touch `_parseFailCount` or the per-1000 counter dump — those are velocity-frame-specific. (Rationale: keep "frames" as the throughput measure of the user's stick.)

Run: `pio test -e native -f test_websocket_control_dispatch` — expect green. Also re-run `test_command_frame_parser` (regression).

**Parallel?** No — depends on 1.2 (ArmingState API) and 1.3 (FrameParseResult shape).

**Done when:** new control-dispatch tests pass; existing producer behaviour unchanged for velocity frames (still routed to latch).

**Commit:** `ws-producer: dispatch control frames to ArmingState`

Files staged: `src/input/WebSocketCommandProducer.cpp`, `src/input/WebSocketCommandProducer.h` (if `dispatchFrame` is a member), `test/test_websocket_control_dispatch/test_websocket_control_dispatch.cpp`.

---

### Step 1.5 — `OtaSafeMode::onStart` calls `ArmingState::disarm()`

**Inputs:** Step 1.2. Files: `src/network/OtaSafeMode.cpp`, `src/safety/ArmingState.h`.

**Tests first** — there is no native-testable path for `ArduinoOTA.onStart` itself (it's an upstream library handler). Instead test the small integration helper:
- Refactor the OTA-start handler into a free function `static void onOtaStart()` in `OtaSafeMode.cpp` that does the three things in order: `g_updating.store(true)`, `ArmingState::disarm()`, `Serial.println("[ota] update starting")`. Expose it via a deliberately-named `OtaSafeMode::detail::onOtaStartForTest()` in a `#ifdef BB8_TEST_HOOKS` block (the `env:native` build_flags already define `BB8_DEBUG`; either reuse that or add `-DBB8_TEST_HOOKS` to `env:native`).
- New test dir `test/test_ota_safe_mode_hooks/test_ota_safe_mode_hooks.cpp`:
  - `test_on_ota_start_disarms` — set ArmingState to Armed; call `OtaSafeMode::detail::onOtaStartForTest()`; assert `ArmingState::get() == Disarmed`.
  - `test_on_ota_start_from_disarmed_is_noop` — ArmingState begins Disarmed; call the helper; assert still Disarmed (no exception, no spurious state change).
  - `test_on_ota_start_from_killed_stays_killed` — ArmingState set to Killed; call helper; assert still Killed (`disarm()` is a no-op when Killed per spec).

Run: expect compile failure (`onOtaStartForTest` doesn't exist).

**Implementation:**
- In `src/network/OtaSafeMode.cpp`:
  - `#include "ArmingState.h"` near the top.
  - Locate the `ArduinoOTA.onStart([]() { ... });` lambda inside `OtaSafeMode::begin()` (post-commit 6b3423b: currently around lines 118-121, but use a textual grep — the file is under active maintenance and exact line numbers drift). The lambda today does only `g_updating.store(true)` and `Serial.println("[ota] update starting")`. **Do not** alter `tryConnectSta` (which sets `WIFI_PS_NONE`), the atomic `g_last_sta_connected_ms`, or any other WiFi-tuning logic — those are out of scope for this step.
  - Move the lambda body into a file-static `static void onOtaStart()` containing:
    ```cpp
    static void onOtaStart() {
        g_updating.store(true, std::memory_order_release);
        ArmingState::disarm();
        Serial.println("[ota] update starting");
    }
    ```
  - Replace the lambda registration with `ArduinoOTA.onStart(onOtaStart);`.
  - Under `#ifdef BB8_TEST_HOOKS`, expose `namespace OtaSafeMode::detail { void onOtaStartForTest() { onOtaStart(); } }`.
- `env:native` in `platformio.ini` gains `-DBB8_TEST_HOOKS`. Existing `BB8_DEBUG` flag is untouched (different concern).
- **No change to `BringUp.h` / `BringUp.cpp`.** `BringUp::begin()` calls `OtaSafeMode::begin()` which now (via this commit) registers a lambda that disarms on OTA start. The dependency goes `OtaSafeMode → ArmingState`; `BringUp` stays unaware of `ArmingState`, preserving the facade.
- Note: the existing `test/test_ota_policy/` covers `OtaPolicy` reboot logic. This new directory tests the integration helper specifically — orthogonal scope.

Run: `pio test -e native -f test_ota_safe_mode_hooks` — green.

**Parallel?** No — depends on 1.2.

**Done when:** new tests pass; `pio run -e robot` compiles (link sanity: ArmingState reachable from OtaSafeMode TU).

**Commit:** `ota: disarm via ArmingState on OTA upload start`

Files staged: `src/network/OtaSafeMode.cpp`, `platformio.ini`, `test/test_ota_safe_mode_hooks/test_ota_safe_mode_hooks.cpp`.

---

### Step 1.6 — `main_robot.cpp` arming gate + dispatcher

**Inputs:** Steps 1.2, 1.4, 1.5. Files: `src/main_robot.cpp`.

**Tests first** — no native test (this is integration glue inside the FreeRTOS task body). Bench-verify after build:
- Build `pio run -e robot` — must succeed.
- After upload: on boot, `RemoteSerial` prints `arming: Disarmed (boot)`. Send `c:arm` from the webapp scratchpad — log shows `arming: Armed`. Send `c:kill` — log shows `arming: Killed`. Send `c:clearkill` — back to `Disarmed`.

**Implementation:**
1. Add `#include "ArmingState.h"` at the top of `main_robot.cpp`.
2. **Setup() ordering — interaction with the BringUp facade.** The current `setup()` starts with `BringUp::begin();` (commits b195fb3 / d6fbf62), which internally does `Serial.begin → OtaSafeMode::begin → RemoteSerial::begin`. The OTA-start lambda is registered inside `OtaSafeMode::begin`, so by the time `BringUp::begin()` returns, the lambda is wired but has not yet fired. Insert `ArmingState::begin()` **immediately after** `BringUp::begin()`. The ordering is defensive (the file-static `std::atomic<State>` is already `Disarmed` at boot via static init, so even an OTA hook firing before `ArmingState::begin()` would call `disarm()` on a Disarmed state — a no-op — but the explicit init removes any doubt).
3. Install `RemoteSerial::onMessage(handleRemoteSerialLine)` **after** `BringUp::begin()` (which calls `RemoteSerial::begin()` internally — installing the message handler before that would lose the callback registration). The dispatcher (file-static) does:
   - Trims the line.
   - Matches `"arm"`, `"disarm"`, `"kill"`, `"clearkill"`, `"armstate"` and calls the matching `ArmingState::` function (or prints state for `armstate`).
   - On no match: prints `RemoteSerial::printf("[cmd] unknown verb: %s\n", line.c_str())`.
4. Modify `controlTask` body, replacing lines 138-159:
   ```cpp
   BodyVelocity drive_cmd{0, 0, 0};

   // Pull freshest command + compute staleness ramp (unchanged from current
   // lines 127-148, but assign result into drive_cmd).
   // ...

   const auto arming = ArmingState::get();
   if (arming == ArmingState::State::Killed) {
       g_controller->stop();
       drive_cmd = {0, 0, 0};
   } else if (arming == ArmingState::State::Armed) {
       // Auto-disarm on producer silence (>2000ms). RobotConstants::STALE_DISARM_MS.
       if (have_seen_fresh && (now - last_fresh_ms) > STALE_DISARM_MS) {
           ArmingState::disarm();
           drive_cmd = {0, 0, 0};
       } else {
           IMUReading imu_reading = g_imu.read();
           g_controller->update(drive_cmd, imu_reading);  // (becomes …, dt) in Phase 2)
       }
   } else {
       // Disarmed: hard-zero, skip controller. Per-wheel PIDs hold motors at 0.
       drive_cmd = {0, 0, 0};
       g_drivetrain.drive(drive_cmd);
   }
   g_drivetrain.update(dt);
   ```
5. Delete the `if (OtaSafeMode::isUpdating()) drive_cmd = {0, 0, 0};` block at current lines 153-155 (per pre-flight decision: arming-state alone gates OTA).
6. Add `STALE_DISARM_MS = 2000` to `src/drivetrain/RobotConstants.h` alongside `STALENESS_TIMEOUT_MS`.
7. Add to top of `setup()` log: `RemoteSerial::println("[arming] boot state: Disarmed");`.

**Parallel?** No — depends on 1.2 / 1.4 / 1.5 all landing first.

**Done when:**
- `pio run -e robot` compiles.
- Bench: boot the robot, webapp scratchpad sends `c:arm` / `c:disarm` / `c:kill` / `c:clearkill` and the state transitions log on RemoteSerial. With `PassthroughDrivetrainController` still wired, an armed-state joystick command moves the wheels; a `c:disarm` immediately stops them.
- Bench: trigger an OTA upload from the IDE while armed; observe `[arming] Armed → Disarmed` in the RemoteSerial log at the moment upload starts.
- Bench: leave producer disconnected for >2s while armed; observe auto-disarm.

**Commit:** `main_robot: gate control task on ArmingState, drop ota check`

Files staged: `src/main_robot.cpp`, `src/drivetrain/RobotConstants.h`.

---

### Step 1.7 — Phase 1 reviewer subagent

Dispatch a reviewer subagent (single `general-purpose` Agent) with the following prompt — verbatim — and pause for its report before starting Phase 2:

> You are reviewing the Phase-1 portion of a balancing-drivetrain feature against its spec. The PR is not yet finished — Phase 2 will land the actual balancing controller. Phase 1 lands the wire-protocol, safety scaffolding, and PID overload.
>
> Read the spec at `code/body-firmware/docs/superpowers/specs/2026-05-13-balancing-drivetrain-controller-design.md`, focusing on the sections: "ArmingState", "Wire protocol — CommandFrameParser", "PID extension", "Arming + control-task integration", "OTA composition".
>
> Read the current diff: `git diff main...HEAD -- code/body-firmware/`. List every commit on the branch.
>
> Check:
> 1. Every spec requirement in the listed sections is implemented in some commit. Cite commit + file.
> 2. Each commit is atomic (one logical change, tests + impl together when applicable, no drive-by edits).
> 3. No `git add -A` or `git add .` was used (check via `git log --stat` for unrelated files).
> 4. No `Co-Authored-By` trailers.
> 5. No testing summaries in commit messages.
> 6. `pio test -e native` passes; `pio run -e robot` compiles. (Run both.)
> 7. The system at HEAD is operationally safe — i.e. `PassthroughDrivetrainController` still wired, boot default DISARMED, OTA disarms on start.
>
> Report findings as a table (issue / location / severity / suggested fix). If you find no issues, say so explicitly. Do not modify code.

If reviewer flags issues, address them as fixup commits on the same branch before Phase 2 begins.

---

# Phase 2 — Balancing controller & tuning

End-state of Phase 2: `BalancingDrivetrainController` is wired into `main_robot.cpp`. `BalanceTuner` registers RemoteSerial verbs that mutate `BalanceConfig` over an atomic-swap pointer slot, persisted to NVS. A separate `main_balance_test.cpp` bench binary lets operators tune without the webapp.

---

### Step 2.1 — `DrivetrainController::update` adds `dt`; update `Passthrough` + existing test

**Inputs:** Spec §"DrivetrainController base class change". Files: `src/drivetrain/controller/DrivetrainController.h`, `src/drivetrain/controller/PassthroughDrivetrainController.h`, `src/main_robot.cpp`, `test/test_passthrough_controller/test_passthrough_controller.cpp`.

**Tests first** — modify `test_passthrough_controller.cpp`:
- Change existing `test_update_forwards_command_to_drivetrain` to call `controller->update(cmd, imuData, 0.01f)` and assert the same outcome (signature change is the test).
- New: `test_update_ignores_dt_value` — call with `dt = 0.01f`, then `dt = 1.0f`, then `dt = 0.0f`; assert `lastDrive` is updated each time and matches `cmd` exactly (no scaling by dt).

Run: `pio test -e native -f test_passthrough_controller` — expect compile failure on the signature.

**Implementation:**
- `DrivetrainController.h` line 20: change pure virtual to `virtual void update(const TCommand& command, const TIMUData& imuData, float dt) = 0;`.
- `PassthroughDrivetrainController.h` line 17: change override to `void update(const BodyVelocity& command, const IMUReading& /*imuData*/, float /*dt*/) override { _drivetrain.drive(command); }`.
- `main_robot.cpp:159`: now `g_controller->update(drive_cmd, imu_reading, dt);` — `dt` is already computed on line 162; move that computation earlier in the loop so both calls use the same value.

Run: `pio test -e native -f test_passthrough_controller` — green. `pio run -e robot` — compiles.

**Parallel?** Yes — independent of every other Phase-2 step. (Anything new in Phase 2 will be written against the new signature.)

**Done when:** existing passthrough tests pass; `main_robot` compiles.

**Commit:** `drivetrain-controller: add dt parameter to update()`

Files staged: `src/drivetrain/controller/DrivetrainController.h`, `src/drivetrain/controller/PassthroughDrivetrainController.h`, `src/main_robot.cpp`, `test/test_passthrough_controller/test_passthrough_controller.cpp`.

---

### Step 2.2 — `BalanceConfig` struct + `RobotConstants::balanceConfig()` factory

**Inputs:** Spec §"BalanceConfig". File: new `src/drivetrain/BalanceConfig.h`, modify `src/drivetrain/RobotConstants.h`.

**Tests first** — new dir `test/test_balance_config/test_balance_config.cpp` (this dir hosts both struct-shape tests and the persistence tests added in 2.5; keep them in the same TU):
- `test_default_config_values_match_spec` — call `RobotConstants::balanceConfig()`; assert each field equals the spec's literals (line 88-100 of spec). One `TEST_ASSERT_FLOAT_WITHIN(1e-6f, expected, actual)` per field.
- `test_config_is_trivially_copyable` — `static_assert(std::is_trivially_copyable<BalanceConfig>::value)` at TU scope.
- `test_envelope_invariant_in_defaults` — assert `envelopeExitSin < envelopeEnterSin` (the spec's validation rule must hold for the defaults).

Run: expect compile failure (`BalanceConfig.h` missing).

**Implementation:**
- Create `src/drivetrain/BalanceConfig.h` with the struct exactly as in spec lines 60-83. POD layout; no constructor. Header-only.
- Add `inline BalanceConfig balanceConfig() { return {...}; }` to `src/drivetrain/RobotConstants.h` with the spec's default values.

Run: green.

**Parallel?** Yes — independent of everything.

**Done when:** struct compiles, defaults test passes, trivially-copyable assertion compiles.

**Commit:** `drivetrain: add BalanceConfig struct and default factory`

Files staged: `src/drivetrain/BalanceConfig.h`, `src/drivetrain/RobotConstants.h`, `test/test_balance_config/test_balance_config.cpp`.

---

### Step 2.3 — `quatToBodyGravity` utility + unit tests

**Inputs:** Spec §"Quaternion → body-frame gravity". File: new `src/drivetrain/controller/quatToBodyGravity.h`. (Keep this as a separate header so the math is unit-testable independent of the controller class — TDD discipline for the sign-convention check.)

**Tests first** — new dir `test/test_quat_to_body_gravity/test_quat_to_body_gravity.cpp`:
- `test_identity_quaternion_yields_zero_zero_minus_one` — `q = {1, 0, 0, 0}`; assert `gx ≈ 0`, `gy ≈ 0`, `gz ≈ -1`. **This test is the sign-convention gate** — if it doesn't pass the formula is wrong.
- `test_pitch_forward_30deg` — `q` representing 30° rotation about body-y axis: `q = {cos(15°), 0, sin(15°), 0}`. Assert `gx ≈ sin(30°) = 0.5` (positive — pitched forward gives positive gx), `gy ≈ 0`, `gz ≈ -cos(30°) ≈ -0.866`.
- `test_roll_left_30deg` — `q = {cos(15°), sin(15°), 0, 0}` (30° about body-x). Assert `gx ≈ 0`, `gy ≈ -sin(30°) = -0.5` (left-roll: gy negative per spec sign convention), `gz ≈ -0.866`.
- `test_full_inversion_180deg_about_x` — `q = {0, 1, 0, 0}`. Assert `gz ≈ +1` (upside-down).
- `test_grid_of_pitch_roll_combinations` — loop pitch ∈ {-30°, -15°, 0, 15°, 30°}, roll ∈ {-30°, ..., 30°}, build the quaternion `q = q_roll * q_pitch` (use a tiny helper), compute analytic ground truth `gx = sin(pitch)`, `gy = -sin(roll)*cos(pitch)`, `gz = -cos(roll)*cos(pitch)`, assert within `1e-4`.

Run: expect compile failure.

**Implementation:**
- Create `src/drivetrain/controller/quatToBodyGravity.h`:
  ```cpp
  #pragma once
  #include "Quat.h"

  inline void quatToBodyGravity(const Quat& q, float& gx, float& gy, float& gz) {
      gx =  2.0f * (q.w * q.y - q.x * q.z);
      gy = -2.0f * (q.w * q.x + q.y * q.z);
      gz = -(q.w*q.w - q.x*q.x - q.y*q.y + q.z*q.z);
  }
  ```
- Header-only; no .cpp.

Run: green.

**Parallel?** Yes — pure math, no dependencies.

**Done when:** all gravity tests pass, especially identity-quaternion test (sign-convention contract).

**Commit:** `imu-math: add quatToBodyGravity utility`

Files staged: `src/drivetrain/controller/quatToBodyGravity.h`, `test/test_quat_to_body_gravity/test_quat_to_body_gravity.cpp`.

---

### Step 2.4 — `BalancingDrivetrainController` class

**Inputs:** Steps 1.1, 2.1, 2.2, 2.3. Spec §"BalancingDrivetrainController" and §"Tilt-fault Schmitt".

**Tests first** — new dir `test/test_balancing_controller/test_balancing_controller.cpp`. Use `MockDrivetrain` and `MockIMU` patterns from `test_passthrough_controller.cpp`. Reusable helpers at file scope: `BalanceConfig makeTestConfig()` returning small known gains, `Quat upright()` returning identity, `Quat pitchedForward(float rad)` returning the appropriate quaternion.

The controller test file owns the `std::atomic<const BalanceConfig*>` slot used as input. Tests written from spec table (lines 524-536):
- `test_zero_command_level_platform_emits_zero` — cmd `{0,0,0}`, `q = upright()`, gyro zero; expect `drive_cmd ≈ {0, 0, 0}`.
- `test_zero_command_pitched_forward_drives_backward` — cmd `{0,0,0}`, `q = pitchedForward(10°)`, gyro zero; expect `vx_out < 0` (controller drives backward to correct). One iteration only — assert sign, not magnitude.
- `test_zero_command_rolled_left_drives_right` — analogous on the roll axis.
- `test_forward_command_level_emits_forward_vx_only` — cmd `{0.5, 0, 0}`, `q = upright()`, gyro zero; expect `vx_out > 0` (after several iterations to overcome derivative), `vy_out == 0`, `omega_out == 0`.
- `test_forward_command_at_target_tilt_settles_to_zero` — pre-compute tilt = `0.30 * 0.5 = 0.15 rad`, build that quaternion, gyro zero; expect `vx_out ≈ 0` (error has converged, no integral built yet).
- `test_enter_fault_above_enter_envelope` — `q` corresponding to 65° pitch (above `envelopeEnterSin = sin(60°)`); cmd nonzero; gyro zero. Pre-load `_pitchPid` with a known integral via warm-up calls, assert post-fault entry the drivetrain.lastDrive is zero AND a follow-up update at level platform doesn't re-emit the stored integral (PID reset on entry).
- `test_in_fault_between_thresholds_stays_in_fault` — first put controller in fault (call with 65°), then call with 57° (between exit 55° and enter 60°); assert still emitting zero.
- `test_exit_fault_below_exit_envelope` — from fault, call with 50° → expect normal operation resumes (non-zero output for a nonzero command).
- `test_output_clamp_at_max_velocity` — feed an enormous setpoint via huge PID gains in the config; assert `|vx_out| ≤ maxOutputVelocity` exactly.
- `test_stop_resets_pid_state_and_calls_drivetrain_stop` — warm up PIDs with several updates, call `controller.stop()`, assert `drivetrain.stopCallCount == 1` and a subsequent `update(level, zero, zero)` emits zero (no leftover integral).

Run: expect compile failures.

**Implementation:**
- Create `src/drivetrain/controller/BalancingDrivetrainController.h` and `.cpp`. Class signature exactly as spec lines 147-166.
- Constructor stashes `_configSlot` reference, builds `_pitchPid` and `_rollPid` from initial config snapshot (or from defaults — either works since the slot is loaded at every `update()` anyway; build PIDs with placeholder bounds `[-maxOutputVel, +maxOutputVel]` from the initial snapshot). PIDs use `outputMin = -cfg.maxOutputVelocity`, `outputMax = +cfg.maxOutputVelocity`, no deadband.
- **Important — PID gains coupling:** the PID class today stores gains in its constructor and has no `setGains()` setter. The controller must either:
  1. Reach into the PID via a new `PID::setGains(kp, ki, kd)` setter (small addition; one extra test in `test_pid` for the setter), OR
  2. Reconstruct PID instances on every config swap (heap-free if PIDs are by-value members and we use placement-new; ugly).
  Pick **option 1**: add `PID::setGains(float kp, float ki, float kd)` in this commit (one-line member-mutation) with a dedicated test (`test_set_gains_changes_output`). Document the new setter in the same commit since it's controller-driven.
- `update(cmd, imu, dt)` body follows spec algorithm lines 168-201:
  1. `const BalanceConfig& cfg = *_configSlot.load(std::memory_order_acquire);`
  2. Push current cfg gains into both PIDs via `setGains` (cheap; lets live tuning take effect).
  3. `quatToBodyGravity(imu.orientation, gx, gy, gz);`
  4. `float tiltMagSin = std::sqrt(gx*gx + gy*gy);`
  5. Schmitt: `if (!_inFault && tiltMagSin > cfg.envelopeEnterSin) { _inFault = true; _pitchPid.reset(); _rollPid.reset(); }` then `if (_inFault) { if (tiltMagSin <= cfg.envelopeExitSin) _inFault = false; else { _drivetrain.drive({0,0,0}); return; } }`. Log fault transitions.
  6. `pitch_target = clamp(cfg.tiltPerVelocity * cmd.vx, -cfg.maxTiltSetpoint, +cfg.maxTiltSetpoint);`
  7. `pitch_actual = std::atan2(gx, -gz);` (and roll analogously).
  8. `float gyro_pitch_rate = cfg.gyroPitchSign * imu.gyro.y;` (and roll = `cfg.gyroRollSign * imu.gyro.x`).
  9. `float vx_out = _pitchPid.compute(pitch_target, pitch_actual, gyro_pitch_rate, dt);` (and vy_out).
  10. Clamp to `±cfg.maxOutputVelocity` (redundant with PID clamp, but the spec asks for an explicit clamp after the PID step — done for safety against PID gain glitches and to keep the spec's algorithm verbatim).
  11. `_drivetrain.drive({vx_out, vy_out, cmd.omega});`
- `stop()` calls `_drivetrain.stop()`, resets both PIDs, sets `_inFault = false`.

Run: `pio test -e native -f test_balancing_controller` and `pio test -e native -f test_pid` (for the new `setGains` test) — all green.

**Parallel?** No — depends on 1.1 (PID 4-arg), 2.1 (controller base), 2.2 (BalanceConfig), 2.3 (quatToBodyGravity).

**Done when:** all 10 balancing-controller test cases pass; `pio run -e robot` compiles.

**Commit:** `drivetrain-controller: add BalancingDrivetrainController`

Files staged: `src/drivetrain/controller/BalancingDrivetrainController.h`, `src/drivetrain/controller/BalancingDrivetrainController.cpp`, `src/control/PID.h` (adds `setGains`), `test/test_balancing_controller/test_balancing_controller.cpp`, `test/test_pid/test_pid.cpp` (one new test for `setGains`).

---

### Step 2.5 — `BalanceConfig` NVS persistence

**Inputs:** Step 2.2. Spec §"Persistence". Files: append to the same `test_balance_config` TU; persistence helpers go in a new header `src/drivetrain/BalanceConfigStorage.h` plus a `.cpp` that wraps `Preferences`.

**Tests first** — extend `test/test_balance_config/test_balance_config.cpp`. Storage tests use a `FakePreferences` stub (under `test/stubs/`) since real `Preferences` is an Arduino class. Pattern: see `test/stubs/` and FFF usage in existing native tests.
- `test_save_then_load_round_trip` — store a non-default `BalanceConfig`; load into a fresh struct; assert every field equals what was stored.
- `test_load_with_missing_blob_returns_defaults` — `FakePreferences::getBytes` returns 0; loader returns `RobotConstants::balanceConfig()`.
- `test_load_with_wrong_size_returns_defaults` — `FakePreferences::getBytes` returns `sizeof(BalanceConfig) - 1`; loader returns defaults.
- `test_load_with_wrong_version_returns_defaults` — write a blob with `version = 0`; load returns defaults.
- `test_save_writes_version_prefix` — call `save(cfg)`; inspect `FakePreferences` bytes; assert first 2 bytes are little-endian `0x01 0x00` (version = 1) followed by `sizeof(BalanceConfig)` bytes matching `cfg`.

Run: expect compile failures.

**Implementation:**
- Create `src/drivetrain/BalanceConfigStorage.h` with:
  ```cpp
  namespace BalanceConfigStorage {
      constexpr uint16_t VERSION = 1;
      bool load(BalanceConfig& out);   // returns false on miss/corrupt; out is then unchanged.
      void save(const BalanceConfig& cfg);
  }
  ```
- Create `src/drivetrain/BalanceConfigStorage.cpp` that uses `Preferences` namespace `"balance"`, key `"config"`, mirroring the BNO055 pattern (begin readOnly→getBytes→end, begin writable→putBytes→end). Blob layout: `[uint16_t version][BalanceConfig payload]`.
- For native tests, behind `#ifdef BB8_NATIVE_TEST` (a new `-D` we add to `env:native`), swap `Preferences` for the fake. Cleanest: include a header `BalanceConfigPrefs.h` that aliases the type; native build aliases to `FakePreferences`. (Or use compile-time templating — pick whichever is uglier.)
- The caller (in main, Phase 2 wire-in step) does: `BalanceConfig boot_cfg; if (!BalanceConfigStorage::load(boot_cfg)) boot_cfg = RobotConstants::balanceConfig();`.

Run: green.

**Parallel?** No — depends on 2.2 (struct).

**Done when:** 5 persistence tests pass; `pio run -e robot` compiles.

**Commit:** `drivetrain: add NVS persistence for BalanceConfig`

Files staged: `src/drivetrain/BalanceConfigStorage.h`, `src/drivetrain/BalanceConfigStorage.cpp`, `test/test_balance_config/test_balance_config.cpp`, `test/stubs/FakePreferences.h` (if not already there), `platformio.ini` (add `-DBB8_NATIVE_TEST` to `env:native` if introduced).

---

### Step 2.6 — `BalanceTuner` + atomic config-swap slot

**Inputs:** Steps 1.2, 2.2, 2.5. Spec §"RemoteSerial tuning" and §"Atomic config swap".

**Tests first** — new dir `test/test_balance_tuner/test_balance_tuner.cpp`. The tuner owns the two-buffer slot internally and exposes it via `BalanceTuner::slot()` for the controller to read. Tests don't need RemoteSerial — they call `BalanceTuner::handle(const String&)` directly. Capture output via a callback the tuner uses instead of `RemoteSerial::printf` (or a function pointer set in `setUp()`).
- `test_show_dumps_current_config` — call `handle("balance show")`; assert captured output contains each field name and value.
- `test_show_pids` — `handle("balance show pids")`; output contains the six gain values, nothing else.
- `test_set_valid_field_updates_slot` — `handle("balance set pitchKp 2.5")`; assert `slot.load()->pitchKp == 2.5f`. Subsequent `show` reflects.
- `test_set_atomic_swap_uses_spare_buffer` — call `set` twice in a row, assert the pointer returned by `slot.load()` flips between two stable addresses (and is never null).
- `test_set_invalid_negative_kp_rejected` — `handle("balance set pitchKp -1.0")`; assert slot unchanged; output contains "error".
- `test_set_invalid_envelope_order_rejected` — try to set `envelopeExitSin > envelopeEnterSin`; rejected.
- `test_set_max_tilt_above_fault_envelope_rejected` — start from defaults; `handle("balance set maxTiltSetpoint 1.10")` (≈63°); rejected because `1.10 ≥ asin(envelopeEnterSin) = asin(0.866) ≈ 1.047 rad (60°)`. Slot unchanged; output mentions the invariant. Without this rule the operator can configure commanded tilt above the fault threshold, where every full-stick command instantly faults.
- `test_set_unknown_key_rejected` — `handle("balance set foo 1.0")`; rejected.
- `test_reset_reverts_to_defaults` — set several fields, then `handle("balance reset")`; assert `*slot.load()` equals `RobotConstants::balanceConfig()`.
- `test_save_invokes_storage` — using the `FakePreferences` fake, call `handle("balance save")`; assert blob was written.
- `test_status_prints_pitch_roll_armed` — assert output contains the expected keys (controller state mock fed via a getter).

Run: expect compile failures.

**Implementation:**
- Create `src/drivetrain/BalanceTuner.h` and `.cpp`:
  - Owns two `BalanceConfig` static buffers and a `std::atomic<const BalanceConfig*>` slot pointing at one.
  - `void begin(const BalanceConfig& initial)` — copies `initial` into buffer A, points slot at A.
  - `std::atomic<const BalanceConfig*>& slot()` — for the controller constructor.
  - `void handle(const String& line)` — parses the verb. Lookup table of field-name → `&BalanceConfig::pitchKp` etc., using pointer-to-member-float. Validation rules per spec line 456-458 PLUS the safety invariant `cfg.maxTiltSetpoint < std::asin(cfg.envelopeEnterSin)` (commanded tilt must sit inside the fault envelope; otherwise full-stick instantly faults). On valid `set`, copy live → spare, mutate spare, validate, `slot.store(spare)`, `vTaskDelay(pdMS_TO_TICKS(CONTROL_PERIOD_MS + 1))` (guarded under `#ifdef ARDUINO`; on native tests, a no-op).
  - Output goes via an injectable `std::function<void(const String&)> _print` defaulting to `RemoteSerial::println` on Arduino, settable in tests.
- The arming verbs (`arm` / `disarm` / `kill` / `clearkill` / `armstate`) are handled by a separate file-static dispatcher in `main_balance_test.cpp` and `main_robot.cpp` (same shape in both; tolerate the small duplication or factor to `src/safety/ArmingHandlers.h`). For this step keep the handlers inline in the main files and write the duplication in 2.7 / 2.8. Acceptable: ~15 lines duplicated.

Run: green.

**Parallel?** No — depends on 1.2, 2.2, 2.5.

**Done when:** all 10 tuner tests pass; atomic swap verified by pointer-comparison test; `pio run -e robot` compiles.

**Commit:** `drivetrain: add BalanceTuner with atomic-swap config slot`

Files staged: `src/drivetrain/BalanceTuner.h`, `src/drivetrain/BalanceTuner.cpp`, `test/test_balance_tuner/test_balance_tuner.cpp`.

---

### Step 2.7 — `main_balance_test.cpp` bench harness + platformio envs

**Inputs:** All Phase 2 steps so far. Files: new `src/main_balance_test.cpp`; modify `platformio.ini`.

**Tests first** — no native tests; this is a top-level main. Build-and-run verification only.

**Implementation:**
- Copy `main_robot.cpp` (the version at HEAD after Step 1.6, which already uses the new `BringUp` facade — `BringUp::begin()` in `setup()` + `BringUp::tick()` in `loop()`, plus `OTA_SAFE_MODE_FOR(...)` at file scope). Reuse that bring-up sequence verbatim — do not hand-roll `Serial.begin()` / `OtaSafeMode::begin()` / `RemoteSerial::begin()` separately. The whole point of commit b195fb3 / 62bc396 / d6fbf62 is that any new `main_*.cpp` gets OTA + WebSerial console with one line.
- Strip from the copy:
  - `WebSocketCommandProducer` and its `start()` / `stop()` call sites — removed entirely.
  - The `links2004/WebSockets` lib dep — not needed (the new `[env:balance_test]` does *not* re-add it).
- **Keep** `CommandLatch<BodyVelocity>` — the bench harness writes from the RemoteSerial AsyncTCP task (Core 0) and reads from the control task (Core 1). Cross-core float assignment is not atomic on Xtensa LX6, so a non-latched `BodyVelocity g_remote_cmd` is racy (one tick can read `vx` from a new command and `vy` from the old one). The race is benign because the operator types at ~1 Hz, but the right shape matches `main_robot.cpp` and costs nothing.
- Add:
  - `OTA_SAFE_MODE_FOR("bb8-balance-test")` at file scope (anchors the OTA-safe-mode link enforcement; required by `OtaSafeMode.h`).
  - `CommandLatch<BodyVelocity> g_remote_latch;` (file-static).
  - `BalanceTuner` instance + initialization in `setup()` after `BNO055IMU.begin()` and after loading the persisted `BalanceConfig` via `BalanceConfigStorage::load`.
  - `BalancingDrivetrainController` instance wired to `g_drivetrain`, `g_imu`, and `tuner.slot()`.
  - `RemoteSerial::onMessage(handleLine)` where `handleLine`:
    - Trims input.
    - Matches `cmd <vx> <vy> <omega>` (regex-light: token by space, `strtof`) — calls `g_remote_latch.write({vx, vy, omega})`. Logs the parsed values.
    - Matches arming verbs (`arm` / `disarm` / `kill` / `clearkill` / `armstate`).
    - Falls through to `BalanceTuner::handle(line)`.
- `setup()` ordering: `BringUp::begin();` → `Wire.begin();` → motors → `g_imu.begin()` → `ArmingState::begin()` → tuner / controller construction → control-task spawn. `BringUp::begin()` must run first so that any later failure leaves the chip OTA-reachable.
- `loop()`: `BringUp::tick();` then `vTaskDelay(...)`. Same as `main_robot.cpp`.
- Control task uses the same shape as `main_robot.cpp` (staleness ramp + arming gate); reads from `g_remote_latch` instead of the WS-fed `g_latch`. The staleness window does the same job here as in `main_robot.cpp` — short-term silence ramps to zero, long-term silence triggers auto-disarm.

> **Note on env extension**: `[env:balance_test]` extends `env:wemos_d1_uno32_ota_console`, which (commit 62bc396) already pulls in WebSerial / AsyncWebServer / AsyncTCP. So the new env does not need to re-list those libs — extending the OTA-console base is sufficient.
- `platformio.ini` — add two envs:
  ```ini
  [env:balance_test]
  extends = env:wemos_d1_uno32_ota_console
  # CommandLatch.cpp is NOT excluded: the bench harness uses it on the
  # RemoteSerial → control-task path to avoid a cross-core race on BodyVelocity.
  build_src_filter = +<*> -<motor/driver/BTS7960Driver.cpp> -<main_original.cpp> -<main_blink.cpp> -<main_drivetrain_test.cpp> -<main_motor_test.cpp> -<main_imu_test.cpp> -<main_webserial_test.cpp> -<main_robot.cpp> -<input/WebSocketCommandProducer.cpp>
  lib_deps =
      ${env:wemos_d1_uno32_ota_console.lib_deps}
      madhephaestus/ESP32Encoder@0.12.0

  [env:balance_test_ota]
  extends = env:balance_test
  upload_protocol = espota
  upload_port = bb8-robot.local
  # Match env:robot_ota's 60s per-block ACK timeout (commit 47a31a9) — consumer
  # Wi-Fi hiccups overrun the espota default 10s, killing legitimate transfers.
  upload_flags =
      --auth=${sysenv.OTA_PASSWORD}
      --timeout=60
  ```
- Add `OTA_SAFE_MODE_FOR("bb8-balance-test")` at file scope.

Verify: `pio run -e balance_test` compiles. Bench-load it onto the robot (post-PR; not blocking).

**Parallel?** No — depends on 2.4 (controller) and 2.6 (tuner).

**Done when:** `pio run -e balance_test` compiles cleanly; OTA env also compiles.

**Commit:** `main: add main_balance_test bench harness + platformio envs`

Files staged: `src/main_balance_test.cpp`, `platformio.ini`.

---

### Step 2.8 — `main_robot.cpp` swap to `BalancingDrivetrainController`

**Inputs:** Phase 2 entirety. File: `src/main_robot.cpp`.

**Tests first** — no native test (integration). Bench verification after build.

**Implementation:**
1. Replace `#include "PassthroughDrivetrainController.h"` with `#include "BalancingDrivetrainController.h"` and `#include "BalanceTuner.h"` + `#include "BalanceConfigStorage.h"`.
2. Replace the global `PassthroughDrivetrainController* g_controller` with `BalancingDrivetrainController* g_controller`. Add a global `BalanceTuner g_tuner;`.
3. In `setup()` after `g_imu.begin()` and before `g_producer->start()`:
   ```cpp
   BalanceConfig boot_cfg;
   if (!BalanceConfigStorage::load(boot_cfg)) {
       boot_cfg = RobotConstants::balanceConfig();
       RemoteSerial::println("[balance] no persisted config; using defaults");
   }
   g_tuner.begin(boot_cfg);
   g_controller = new BalancingDrivetrainController(g_drivetrain, g_imu, g_tuner.slot());
   ```
4. The RemoteSerial line dispatcher (added in Step 1.6) now falls through to `g_tuner.handle(line)` after the arming verbs.
5. `PassthroughDrivetrainController` stays in the tree — `main_drivetrain_test.cpp` continues to use it. Do not delete the header or its test.

Verify:
- `pio run -e robot` compiles.
- `pio run -e drivetrain_test` still compiles (Passthrough used elsewhere).
- `pio test -e native` all green.

**Parallel?** No — depends on 2.4, 2.5, 2.6.

**Done when:** `main_robot` compiles, all native tests pass, `drivetrain_test` env compiles.

**Commit:** `main_robot: swap to BalancingDrivetrainController`

Files staged: `src/main_robot.cpp`.

---

### Step 2.9 — Bench-verification commit (docs + checklist)

**Inputs:** Spec §"Hardware verification (bench)" and §"Tuning guide".

**Tests first** — N/A (this is a documentation commit, not code).

**Implementation:**
- Create `code/body-firmware/docs/superpowers/runbooks/2026-05-13-balance-bringup.md`:
  - Bench-verification sequence from spec lines 567-579 (steps 1-8) as a numbered list.
  - Sign-convention check sub-procedure for `gyroPitchSign` / `gyroRollSign` (spec lines 191-198).
  - **Axis diagnosis section** distinguishing the two failure modes the spec conflates under "inverted axis":
    > Tilt the platform forward by hand and watch the wheels.
    > - **Wheels drive in the wrong direction on forward tilt** (sign-inverted axis) → set `gyroPitchSign = -1.0` via `balance set gyroPitchSign -1.0`. Live, no reflash.
    > - **Wheels drive *sideways* on forward tilt** (rotated mount: chip-Y points along body-X, etc.) → the two `BalanceConfig` sign knobs cannot fix this. Either physically remount the BNO055 so chip-X aligns with body-forward, or call `_bno.setAxisRemap(...)` in `BNO055IMU::begin()` and reflash. Re-run the bring-up procedure after.
    > Repeat the diagnosis for roll on body-X.
  - Tuning-guide table from spec lines 597-610 reproduced verbatim.
  - Persistence smoke test: `balance set pitchKp 2.0`, `balance save`, reboot, `balance show pids` — assert `pitchKp == 2.0`.
  - Configuration footgun list: `maxTiltSetpoint` must stay strictly below `asin(envelopeEnterSin)`; the tuner enforces this, but if the operator sees a "rejected" message on `set`, this is the invariant they violated.
- This runbook is the operator's reference during bring-up; it's separate from the spec (which lives next to the design) so the operator can update it as bench notes accumulate.

**Parallel?** Yes (doc only) — but logically comes after 2.7 / 2.8 since it references them.

**Done when:** runbook is written, scannable, and lists every bench check the spec requires.

**Commit:** `docs: add balance-controller bring-up runbook`

Files staged: `code/body-firmware/docs/superpowers/runbooks/2026-05-13-balance-bringup.md`.

---

### Step 2.10 — Phase 2 / Final reviewer subagent

Dispatch a reviewer subagent with this prompt — verbatim:

> You are reviewing the full diff of a PR that implements a balancing drivetrain controller. The spec is at `code/body-firmware/docs/superpowers/specs/2026-05-13-balancing-drivetrain-controller-design.md`.
>
> The PR has two logical phases:
> - Phase 1 (wire protocol, ArmingState, PID overload) — should already have passed an earlier review.
> - Phase 2 (BalanceConfig, BalancingDrivetrainController, BalanceTuner, NVS persistence, bench harness, wire-in).
>
> Run `git log main..HEAD --oneline` and `git diff main...HEAD --stat` to see scope.
>
> Audit:
> 1. **Spec coverage**: walk every section of the spec; for each requirement, cite the commit + file + lines that implement it. Flag any missing requirement.
> 2. **Atomic commits**: each commit one logical change. No drive-by edits. No `Co-Authored-By` trailers. No `git add -A`.
> 3. **TDD discipline**: every step has a test commit (or tests in the same commit as impl); no untested public APIs added. Tests come *before* implementation in the diff history where possible.
> 4. **Sign conventions are tested, not just runtime-verified**:
>    - `quatToBodyGravity({1,0,0,0})` → `(0, 0, -1)`. (Test exists.)
>    - `BalancingDrivetrainController` test: zero-cmd-tilted-forward emits `vx_out < 0`. (Test exists.)
>    - `BalancingDrivetrainController` test: zero-cmd-rolled-left emits `vy_out > 0` (or `< 0` per the sign convention chosen — confirm consistency).
>    - The 60°/55° Schmitt threshold is tested with explicit pre-fault → fault → recovery transitions.
> 5. **Cross-file consistency**: `update(cmd, imu, dt)` signature matches across `DrivetrainController.h`, `PassthroughDrivetrainController.h`, `BalancingDrivetrainController.h`, and both `main_*.cpp` call sites.
> 6. **Safety state**: at HEAD, boot default is `Disarmed`; OTA upload disarms; producer silence >2s auto-disarms. Trace each via commit + line.
> 7. **PR body**: uses tables, no checkbox test plan, no testing summary.
> 8. **Build & tests**: run `pio test -e native` and `pio run -e robot` and `pio run -e balance_test`. All three must pass.
>
> Report findings as a table: `requirement | implementation site | severity (BLOCKER/MAJOR/MINOR/NIT) | suggested fix`. If you find no blockers, say so explicitly. Do not modify code.

If the reviewer flags blockers, address them as fixup commits before opening / merging the PR.

---

## PR body (paste at PR open time)

Use this skeleton (tables only, no checkboxes, no testing summary):

```markdown
## Summary

Adds a tilt-balancing inner loop for the BB-8 drivetrain. Replaces `PassthroughDrivetrainController` with `BalancingDrivetrainController` behind an explicit arm/disarm/kill control plane on the existing WebSocket wire protocol. Live PID tuning over RemoteSerial with NVS persistence.

## Phases

| Phase | Scope |
| --- | --- |
| 1 | PID 4-arg overload, ArmingState, sigil-dispatch parser, WS control-frame dispatcher, OTA-disarm hook, control-task arming gate. End-state still uses passthrough controller; behaviour unchanged for drivers (system boots `Disarmed`). |
| 2 | BalanceConfig + NVS, quat→gravity utility, BalancingDrivetrainController, BalanceTuner, `main_balance_test` bench harness + platformio envs, wire-in to `main_robot.cpp`. |

## New wire format

| Frame | Example | Effect |
| --- | --- | --- |
| Velocity (legacy) | `1.0,0.5,0.3` | parsed as `BodyVelocity` (back-compat) |
| Velocity (prefixed) | `v1.0,0.5,0.3` | same as legacy |
| Control | `c:arm` / `c:disarm` / `c:kill` / `c:clearkill` | invokes `ArmingState` transition |

## Safety model

| State | Drive command | Controller call | Drivetrain |
| --- | --- | --- | --- |
| Armed | user input | `update(cmd, imu, dt)` | runs |
| Disarmed | hard-zero | skipped | runs (PIDs hold motors at 0) |
| Killed | n/a | `stop()` | hard brake |

OTA upload starts → `disarm()` automatically. Producer silence >2 s → auto-disarm.

## Bench bring-up

See `docs/superpowers/runbooks/2026-05-13-balance-bringup.md`.
```

## Verification (end-to-end, before opening PR)

| Command | Expected |
| --- | --- |
| `pio test -e native` | all green |
| `pio run -e robot` | compiles |
| `pio run -e drivetrain_test` | compiles (Passthrough still works) |
| `pio run -e balance_test` | compiles |
| Bench: boot, send `c:arm`, joystick forward | platform tilts forward, sphere rolls |
| Bench: tilt platform past 60° | drive halts, fault logged; return below 55° → resume |
| Bench: `c:kill` during motion | wheels brake immediately |
| Bench: OTA upload while armed | `[arming] Armed → Disarmed` log at upload start |
| Bench: `balance set pitchKp 2.0`, `balance save`, reboot, `balance show pids` | pitchKp == 2.0 |

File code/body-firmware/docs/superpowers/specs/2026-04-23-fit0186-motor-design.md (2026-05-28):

# FIT0186Motor Concrete Implementation — Design Spec

## Context

The body-firmware project has a complete set of abstract interfaces but no concrete implementations. The team has received the physical hardware (BTS7960 H-bridge drivers + FIT0186 DC geared motors with Hall-effect quadrature encoders). This spec covers:

1. Reorganizing `src/` into domain subdirectories (committed on main)
2. Implementing the concrete motor stack: `Driver` abstraction, `BTS7960Driver`, and `FIT0186Motor` (on a feature branch)

## Phase 1: Project Setup (on main)

Two commits: directory reorganization, then testing infrastructure.

### Target layout

```
src/
  main.cpp
  config/
  motor/
    Motor.h
    constants/
    driver/
  drivetrain/
    Drivetrain.h
    controller/
      DrivetrainController.h
  imu/
    IMU.h
  input/
    InputSource.h
    CommandBuffer.h
  control/
    PID.h
  util/
```

### Commit 1: Directory reorganization

- `git mv` each header to its new location
- Update all `#include` paths in `main.cpp`
- Add `-I` flags to `platformio.ini` for each subdirectory:
  ```
  -Isrc/config -Isrc/motor -Isrc/motor/constants -Isrc/motor/driver -Isrc/drivetrain -Isrc/drivetrain/controller -Isrc/imu -Isrc/input -Isrc/control -Isrc/util
  ```
- Verify `pio run` compiles

### Commit 2: Testing infrastructure

Add a `[env:native]` environment for running tests on the host machine (no ESP32):

```ini
[env:native]
platform = native
build_flags =
    -std=gnu++17
    -Wall
    -Wextra
    -Isrc/config
    -Isrc/motor
    -Isrc/motor/constants
    -Isrc/motor/driver
    -Isrc/drivetrain
    -Isrc/drivetrain/controller
    -Isrc/imu
    -Isrc/input
    -Isrc/control
    -Isrc/util
    -DBB8_DEBUG
```

PlatformIO uses Unity (C test framework) by default for native tests. Tests live in `test/`:

```
test/
  test_native/        — tests that run on host (pure logic, mocks)
```

Verify with `pio test -e native`.

## Phase 2: Motor Stack Implementation (on feature branch)

Branch: `feature/motor-impl`

### Updated Motor Interface

`src/motor/Motor.h`:

```cpp
class Motor {
public:
    virtual ~Motor() = default;
    virtual void begin() = 0;
    virtual void update() = 0;               // refresh encoder/RPM state; call at fixed interval
    virtual void setSpeed(float speed) = 0;  // [-1.0, 1.0], 0.0 = coast
    virtual void brake() = 0;                // active stop (shorts terminals)
    virtual float getRPM() = 0;              // raw, cached from last update()
    virtual float getFilteredRPM() = 0;      // smoothed via moving average
};
```

- `begin()` — deferred hardware init (Arduino pattern; ESP32 peripherals not ready at static construction time). Seeds timing state (`_lastUpdateMicros`, `_lastCount`) so the first `update()` produces RPM = 0, not garbage.
- `update()` — refresh encoder readings and compute RPM. Called at a fixed interval from the control loop (via `Drivetrain::update()`).
- `setSpeed(0)` — coast (both H-bridge outputs LOW, motor disconnected)
- `brake()` — active braking (both H-bridge outputs HIGH, terminals shorted)
- `getRPM()` / `getFilteredRPM()` — return cached values computed by last `update()` call

**Convention:** All member variables use leading underscore (`_member`) to match existing codebase.

### New Files

#### `src/config/debug.h`

Project-wide defensive programming macros:

- `BB8_ASSERT(cond, msg)` — in debug: logs via ArduinoLog (`Log.fatal`) with file/line, then calls `abort()` (triggers ESP32 panic handler with backtrace). In release (`#ifndef BB8_DEBUG`): compiles to `((void)0)`.
- Uses ArduinoLog for all output. ArduinoLog itself is stripped in release via `DISABLE_LOGGING`.

#### `src/config/pins.h`

```cpp
#include "MotorConfig.h"
#include "FIT0186.h"

// Motor 0
inline constexpr MotorConfig MOTOR0 {
    .driverPins = { ... },
    .encoderPins = { ... },
    .encoderCPR = fit0186::ENCODER_CPR
};
// Motor 1
inline constexpr MotorConfig MOTOR1 {
    .driverPins = { ... },
    .encoderPins = { ... },
    .encoderCPR = fit0186::ENCODER_CPR
};
// Motor 2
inline constexpr MotorConfig MOTOR2 {
    .driverPins = { ... },
    .encoderPins = { ... },
    .encoderCPR = fit0186::ENCODER_CPR
};
```

Pin values TBD based on physical wiring. Motor constants come from `motor/constants/FIT0186.h`. Structure allows changing all config in one file.

#### `src/motor/MotorConfig.h`

```cpp
struct DriverPins {
    uint8_t rpwm;      // H-bridge forward PWM pin
    uint8_t lpwm;      // H-bridge reverse PWM pin
};

struct EncoderPins {
    uint8_t a;          // Quadrature channel A
    uint8_t b;          // Quadrature channel B
};

struct MotorConfig {
    DriverPins driverPins;
    EncoderPins encoderPins;
    uint16_t encoderCPR;  // counts per revolution at gearbox output
};
```

#### `src/motor/constants/FIT0186.h`

Hardware constants for the DFRobot FIT0186 motor:

```cpp
#pragma once
#include <cstdint>

namespace fit0186 {
    inline constexpr uint16_t ENCODER_CPR = 700;  // counts per revolution at gearbox output
    inline constexpr float GEAR_RATIO = 43.8f;
    inline constexpr uint16_t NO_LOAD_RPM = 251;
}
```

#### `src/motor/driver/Driver.h`

Abstract H-bridge driver interface:

```cpp
class Driver {
public:
    virtual ~Driver() = default;
    virtual void begin() = 0;
    virtual void setOutput(float value) = 0;  // [-1.0, 1.0], 0.0 = coast
    virtual void brake() = 0;                 // active stop
};
```

#### `src/motor/driver/BTS7960Driver.h` / `BTS7960Driver.cpp`

Concrete `Driver` implementation wrapping the Arduino-BTS7960 library.

**Constructor** — two overloads:
- `BTS7960Driver(DriverPins pins)` — delegates to individual-arg constructor
- `BTS7960Driver(uint8_t rpwm, uint8_t lpwm)`
- Stores pin config, does NOT touch hardware

**begin()** — initializes BTS7960 PWM channels

**setOutput(float value)** — `BB8_ASSERT` that value is in [-1.0, 1.0]. Maps normalized float to BTS7960 PWM. Positive = RPWM, negative = LPWM, zero = both LOW (coast).

**brake()** — drives both RPWM and LPWM HIGH to short motor terminals

#### `src/motor/FIT0186Motor.h` / `FIT0186Motor.cpp`

Concrete `Motor` implementation. Owns a `Driver&` reference and an `ESP32Encoder` instance.

**Class template**: `template <size_t FilterN = 5> class FIT0186Motor : public Motor`

FilterN is the moving average window size (compile-time). Default of 5 samples.

**Constructor** — two overloads:
- `FIT0186Motor(Driver& driver, EncoderPins encoderPins, uint16_t encoderCPR)`
- `FIT0186Motor(Driver& driver, MotorConfig config)` — extracts encoder fields from config
- Stores config, does NOT touch hardware

**begin()** — calls `_driver.begin()`, attaches ESP32Encoder on encoder pins. Seeds `_lastUpdateMicros = micros()` and `_lastCount = encoder.getCount()` so first `update()` produces RPM = 0.

**update()** — tracks timing via `micros()` delta. Snapshots encoder count (`int64_t`), computes RPM:
```
now = micros()
dtSeconds = (now - _lastUpdateMicros) / 1'000'000.0f
deltaCount = encoder.getCount() - _lastCount  // int64_t arithmetic
rpm = (static_cast<float>(deltaCount) / static_cast<float>(_encoderCPR)) * (60.0f / dtSeconds)
```
Pushes raw RPM into MovingAverage. `_lastCount` is `int64_t` to match `ESP32Encoder::getCount()`.

**setSpeed(float speed)** — delegates to `_driver.setOutput(speed)`

**brake()** — delegates to `_driver.brake()`

**getRPM()** — returns last raw RPM (cached from update())

**getFilteredRPM()** — returns MovingAverage output (returns 0.0f if no samples yet)

**Lifetime requirement:** `Driver&` passed to constructor must outlive the `FIT0186Motor` instance.

#### `src/util/MovingAverage.h`

Header-only template class:

```cpp
template <size_t N>
class MovingAverage {
    static_assert(N > 0, "Window size must be at least 1");
public:
    void push(float value);
    float average() const;  // returns 0.0f when empty
    void reset();
private:
    std::array<float, N> _buffer{};
    size_t _index = 0;
    size_t _count = 0;
};
```

Compile-time window size via template parameter. Reusable for IMU smoothing, PID derivative filtering, etc.

### platformio.ini Changes

```ini
build_flags =
    -std=gnu++17
    -Wall
    -Wextra
    -Isrc/config
    -Isrc/motor
    -Isrc/motor/constants
    -Isrc/motor/driver
    -Isrc/drivetrain
    -Isrc/drivetrain/controller
    -Isrc/imu
    -Isrc/input
    -Isrc/control
    -Isrc/util
    -DBB8_DEBUG
build_unflags = -std=gnu++11
lib_deps =
    luisllamasbinaburo/Arduino-BTS7960
    madhephaestus/ESP32Encoder
    thijse/ArduinoLog
```

Remove `-DBB8_DEBUG` for release builds. ArduinoLog stripped via `DISABLE_LOGGING` define when needed.

### Hardware Reference

- **Motor**: DFRobot FIT0186 — 12V, 251 RPM no-load, 7A stall, 43.8:1 gear ratio
- **Encoder**: Hall-effect quadrature, 16 CPR motor shaft / 700 CPR gearbox shaft
- **Driver**: BTS7960 H-bridge, PWM + direction control
- **RPM resolution**: at 251 RPM and 10ms update interval, ~29 encoder ticks per sample

## Verification

### Phase 1 (project setup)

**Commit 1 — reorganization:**
- `pio run` compiles with no errors/warnings
- All `#include` directives in `main.cpp` resolve to the new paths
- No headers left in `src/` root (except `main.cpp`)
- Each subdirectory contains the expected files per the target layout

**Commit 2 — testing infrastructure:**
- `[env:native]` added to `platformio.ini` with matching `-I` flags and `-std=gnu++17`
- `test/test_native/` directory exists with a minimal test file (e.g. a single passing assertion)
- `pio test -e native` runs the test and reports success
- `pio run` (ESP32 env) still compiles without regression

### Phase 2 (Motor implementation — TDD)
Native tests (`pio test -e native`):
- MovingAverage: push/average, empty returns 0.0f, reset, wraparound
- RPM calculation logic with known encoder deltas
- FIT0186Motor with MockDriver: setSpeed delegates, brake delegates, update computes correct RPM
- BB8_ASSERT fires on out-of-range setOutput in debug build

Hardware verification (upload to ESP32):
- `begin()` initializes without crash
- `setSpeed(0.5)` spins a motor forward
- `setSpeed(-0.5)` spins reverse
- `setSpeed(0)` coasts
- `brake()` stops quickly
- `getRPM()` returns non-zero while spinning
- `getFilteredRPM()` returns a smoother curve than `getRPM()`

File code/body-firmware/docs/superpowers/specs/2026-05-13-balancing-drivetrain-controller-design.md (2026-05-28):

# BalancingDrivetrainController — Design Spec

## Context

Body-firmware has a complete drivetrain (OmniDrivetrain + per-wheel PID) and a
BNO055 IMU on the platform. Today's teleop routes the user's `BodyVelocity`
directly to `drivetrain.drive()` via `PassthroughDrivetrainController` — no IMU
feedback, no balancing.

This spec replaces the passthrough controller with a Segway-style balancing
controller that:
- Derives a tilt setpoint from the user's `BodyVelocity` command and uses
  IMU feedback to drive the platform to that tilt.
- When idle (`cmd = 0`), holds the platform level; the resulting wheel motion
  decelerates the sphere.
- Faults safely when tilt exceeds a 60° envelope.
- Runs only under explicit arm/disarm/kill control.
- Exposes live PID tuning over RemoteSerial, persisted to NVS.

OTA (`OtaSafeMode`) and OmniDrivetrain are unchanged.

## Architecture

```
joystick ──► WebSocket ──► CommandFrameParser ─┬─► CommandLatch<BodyVelocity> ─► control task @100Hz
                                               │
                                               └─► ArmingState transitions (arm/disarm/kill)

control task:
   if (ArmingState::isArmed() && !OtaSafeMode::isUpdating())
       controller.update(cmd, imu, dt)
   else
       controller.stop(); drive_cmd = 0

controller.update():
   cfg = configSlot.load()
   (gx, gy, gz) = quatToBodyGravity(imu.orientation)
   tiltMagSin   = sqrt(gx² + gy²)
   schmitt fault on tiltMagSin against cfg.envelopeEnter/ExitSin
   pitch_target = clamp(cfg.tiltPerVelocity · cmd.vx, ±cfg.maxTiltSetpoint)
   roll_target  = clamp(cfg.tiltPerVelocity · cmd.vy, ±cfg.maxTiltSetpoint)
   pitch_actual = atan2(gx, -gz)        roll_actual  = atan2(gy, -gz)
   vx_out = pitchPid.compute(pitch_target, pitch_actual, gyro_pitch_rate, dt)
   vy_out = rollPid.compute( roll_target,  roll_actual,  gyro_roll_rate,  dt)
   clamp(vx_out, vy_out, cfg.maxOutputVelocity)
   drivetrain.drive({vx_out, vy_out, cmd.omega})
```

Two independent safety layers gate the controller:
- `ArmingState` — explicit operator control (DISARMED / ARMED / KILLED).
- `OtaSafeMode::isUpdating()` — existing OTA halt (unchanged).

A third, internal-only safety (Schmitt tilt-fault) sits inside the controller
itself and halts driving when tilt exceeds the safe envelope.

## New types

### `BalanceConfig` — `src/drivetrain/BalanceConfig.h`

```cpp
struct BalanceConfig {
    // Command → tilt-setpoint mapping
    float tiltPerVelocity;     // rad per (m/s)
    float maxTiltSetpoint;     // rad; clamp on commanded tilt

    // Pitch PID (forward/back)
    float pitchKp, pitchKi, pitchKd;
    // Roll PID (left/right) — separate so platform asymmetries can be tuned
    float rollKp,  rollKi,  rollKd;

    // Output safety
    float maxOutputVelocity;   // m/s; clamp on |vx_out|, |vy_out|

    // Tilt-fault Schmitt thresholds — stored as sin(angle) for cheap compare
    float envelopeEnterSin;    // sin(60°) ≈ 0.866
    float envelopeExitSin;     // sin(55°) ≈ 0.819

    // Gyro axis sign overrides. Default +1; bring-up may set to -1 if the
    // BNO055 axis convention disagrees with our pitch/roll sign assumptions.
    float gyroPitchSign;       // multiplies imu.gyro.y when computing pitch rate
    float gyroRollSign;        // multiplies imu.gyro.x when computing roll rate
};
```

Defaults from `RobotConstants::balanceConfig()`:

```cpp
inline BalanceConfig balanceConfig() {
    return {
        .tiltPerVelocity   = 0.30f,   // 1 m/s → ~17° tilt
        .maxTiltSetpoint   = 0.35f,   // ~20°; leaves ample headroom below 60° fault envelope
        .pitchKp = 1.50f, .pitchKi = 0.0f, .pitchKd = 0.15f,
        .rollKp  = 1.50f, .rollKi  = 0.0f, .rollKd  = 0.15f,
        .maxOutputVelocity = 1.00f,   // m/s; just below physical max (~1.05)
        .envelopeEnterSin  = 0.866f,  // sin(60°)
        .envelopeExitSin   = 0.819f,  // sin(55°)
        .gyroPitchSign     = 1.0f,
        .gyroRollSign      = 1.0f,
    };
}
```

All values are placeholders — actual values come from bench tuning over
RemoteSerial. Defaults are conservative enough to compile, arm, and not
destroy hardware on first run.

### `TiltSetpoint` (internal only)

Used inside the controller for readability. Not a wire-level type.

```cpp
struct TiltSetpoint { float pitch; float roll; };  // rad, body-frame
```

### `ArmingState` — `src/safety/ArmingState.{h,cpp}`

```cpp
namespace ArmingState {
    enum class State : uint8_t { Disarmed, Armed, Killed };

    void  begin();           // initialise to Disarmed
    State get();             // lock-free atomic load
    bool  isArmed();         // shorthand

    void arm();              // Disarmed → Armed (no-op if Killed)
    void disarm();           // Armed    → Disarmed (no-op if Killed)
    void kill();             // any      → Killed
    void clearKill();        // Killed   → Disarmed only
}
```

Stored as `std::atomic<State>` (`uint8_t` underlying; lock-free on ESP32 /
Xtensa LX6). Memory ordering: writers use `store(release)`, readers
(control task hot path) use `load(acquire)`. Single-writer invariant
documented: all transition functions are only called from Core 0
(RemoteSerial dispatcher, WebSocket dispatcher, OtaSafeMode::onStart). No
`compare_exchange` needed.

Each transition logs to `Serial` and `RemoteSerial`. Boot default
`Disarmed` — robot cannot move until first `arm`.

## BalancingDrivetrainController

`src/drivetrain/controller/BalancingDrivetrainController.{h,cpp}`

```cpp
class BalancingDrivetrainController
    : public DrivetrainController<BodyVelocity, IMUReading, BodyVelocity>
{
public:
    BalancingDrivetrainController(Drivetrain<BodyVelocity>& drive,
                                  IMU<IMUReading>& imu,
                                  std::atomic<const BalanceConfig*>& configSlot);

    void update(const BodyVelocity& cmd,
                const IMUReading& imu,
                float dt) override;
    void stop() override;

private:
    PID  _pitchPid;
    PID  _rollPid;
    bool _inFault = false;
    std::atomic<const BalanceConfig*>& _configSlot;
};
```

### `update(cmd, imu, dt)` algorithm

1. Snapshot config: `const BalanceConfig& cfg = *_configSlot.load(std::memory_order_acquire);`
2. Derive body-frame gravity from the quaternion (see "Quaternion → gravity").
3. `tiltMagSin = sqrt(gx² + gy²)`.
4. Schmitt fault state machine on `tiltMagSin` vs
   `(envelopeEnterSin, envelopeExitSin)`. If in fault, emit zero and return.
   On fault entry, reset both balance PIDs.
5. `pitch_target = clamp(cfg.tiltPerVelocity · cmd.vx, ±cfg.maxTiltSetpoint)`;
   roll symmetric.
6. `pitch_actual = atan2(gx, -gz)`; roll symmetric.
7. PID with explicit rate (gyro as derivative source):
   ```
   vx_out = _pitchPid.compute(pitch_target, pitch_actual, gyro_pitch_rate, dt)
   vy_out = _rollPid.compute( roll_target,  roll_actual,  gyro_roll_rate,  dt)
   ```
   Mapping committed:
   - `gyro_pitch_rate = SIGN_PITCH * imu.gyro.y` (pitch = rotation about body-y; right-hand rule with thumb along +y)
   - `gyro_roll_rate  = SIGN_ROLL  * imu.gyro.x` (roll  = rotation about body-x)

   `SIGN_PITCH` and `SIGN_ROLL` are `+1` by default and verified at bring-up
   with this procedure (documented in the bench-harness):

   1. Place platform level. Confirm `gx ≈ 0`, `gy ≈ 0`, `gz ≈ -1`.
   2. Tilt platform forward slowly. Confirm `pitch_actual` increases monotonically and `imu.gyro.y` is non-zero with consistent sign during the tilt.
   3. Numerically integrate `imu.gyro.y` over the motion and compare to the change in `pitch_actual`. If they have opposite signs, set `SIGN_PITCH = -1`.
   4. Repeat for roll with `imu.gyro.x`.

   The two signs are constants in `BalanceConfig` (`gyroPitchSign`, `gyroRollSign`)
   so they're configurable via RemoteSerial without reflash if bring-up reveals
   an inverted axis.
8. Clamp `vx_out`, `vy_out` to `±cfg.maxOutputVelocity`.
9. `omega_out = cmd.omega` (passthrough).
10. `drivetrain.drive({vx_out, vy_out, omega_out})`.

### `stop()`

- `drivetrain.stop()` — brakes wheels and resets per-wheel PIDs.
- Reset `_pitchPid` and `_rollPid`.
- `_inFault = false`.

Called only on hard shutdown (e.g. KILLED state). Distinct from internal
tilt-fault behaviour, which performs a *soft* halt (zero `BodyVelocity` to
`drivetrain.drive()`, no brake) so per-wheel PIDs ramp wheels to zero
gracefully and the controller can resume when tilt re-enters the envelope.

### Quaternion → body-frame gravity

The orientation quaternion `q = (w, x, y, z)` rotates body-frame vectors into
world frame, i.e. `v_world = R(q) · v_body`. To express world-frame gravity
`(0, 0, -1)` in body frame: `g_body = R(q)^T · (0, 0, -1)`, which gives:

```cpp
static void quatToBodyGravity(const Quat& q, float& gx, float& gy, float& gz) {
    // Body-frame components of gravity (world −z, magnitude 1).
    // Reduces to (0, 0, −1) when q = identity (upright platform).
    gx =  2.0f * (q.w * q.y - q.x * q.z);
    gy = -2.0f * (q.w * q.x + q.y * q.z);
    gz = -(q.w*q.w - q.x*q.x - q.y*q.y + q.z*q.z);
}
```

Verify the formula at compile-time with a quaternion unit test (identity →
`(0, 0, −1)`; 30° pitch-forward rotation → `gx > 0`, `gz ≈ −cos 30°`).

Avoids the BNO055 Euler "automatic orientation detection" discontinuity (per
Adafruit / Bosch guidance: read the quaternion, derive Euler-like quantities
in software at the last moment).

Body-frame axis sign convention is verified empirically on first bring-up:
tilt the platform forward by hand, confirm `gx > 0`. If the BNO055 axis
silkscreen is rotated relative to the platform's "forward" direction, the
fix is to swap or negate components *at this single call site*, not anywhere
downstream.

## `DrivetrainController` base class change

The existing base signature is `update(const TCommand&, const TIMUData&)` —
no `dt`. The balancing controller needs `dt` for PID. Update the base:

```cpp
template <typename TCommand, typename TIMUData, typename TVelocity>
class DrivetrainController {
public:
    virtual void update(const TCommand& cmd, const TIMUData& imu, float dt) = 0;
    virtual void stop() = 0;
    ...
};
```

`PassthroughDrivetrainController::update` is updated to accept and ignore
`dt` (`void update(..., float /*dt*/)`). All call sites — currently just
`main_robot.cpp` and the `test_passthrough_controller` test — are updated
to pass `dt` (already computed locally in the control task for
`drivetrain.update(dt)`).

## PID extension

`src/control/PID.h` — add a rate-aware overload.

```cpp
class PID {
public:
    // Existing — finite-difference derivative computed internally.
    float compute(float setpoint, float measurement, float dt);

    // New — caller supplies rate = d(measurement)/dt (e.g. gyro).
    float compute(float setpoint, float measurement, float rate, float dt);
    ...
};
```

The 3-arg version becomes a thin wrapper:

```cpp
float PID::compute(float setpoint, float measurement, float dt) {
    float rate = _firstCompute ? 0.0f : (measurement - _prevMeasurement) / dt;
    return compute(setpoint, measurement, rate, dt);
}
```

The 4-arg version is the canonical implementation. Anti-windup, deadband,
output clamping, sign convention of `derivative = -rate` (derivative on
measurement, same as before) all unchanged.

Per-wheel PIDs in `OmniDrivetrain` continue calling the 3-arg version.
Balance PIDs call the 4-arg version with gyro components.

## Tilt-fault Schmitt

State: `bool _inFault` (initially false).

| Current state | Condition | Action |
| --- | --- | --- |
| not in fault  | `tiltMagSin > envelopeEnterSin` | enter fault: reset balance PIDs, emit zero, log |
| not in fault  | `tiltMagSin ≤ envelopeEnterSin` | normal operation |
| in fault | `tiltMagSin > envelopeExitSin` | stay in fault, emit zero |
| in fault | `tiltMagSin ≤ envelopeExitSin` | exit fault, log, resume normal operation |

The 5° dead band between 60° (enter) and 55° (exit) prevents chatter under
IMU noise at the boundary. PID reset on entry prevents wind-up during the
fault from kicking the wheels when the controller re-engages.

The fault is recoverable — it auto-clears when the platform returns to the
safe envelope. Distinct from `KILLED`, which is latched and requires explicit
operator action.

## Arming + control-task integration

Three behaviours, gated solely by `ArmingState`. OTA composes by *driving*
the state (see "OTA composition" below), not by a separate check in the
hot path.

| State | drive_cmd | `controller.update()` | Drivetrain |
| --- | --- | --- | --- |
| `ARMED` | user (`CommandLatch`) | called normally | runs |
| `DISARMED` | hard-zeroed | **skipped** | runs (PIDs hold motors at zero) |
| `KILLED` | n/a | replaced by `stop()` | hard brake |

Rationale: `DISARMED` is "robot off" — no balance assistance, motors held
electrically at zero by the per-wheel PIDs. The platform pendulums passively.
This is the safe default and is what we want during OTA flash. `ARMED` is
the only state in which the balance loop is active. `KILLED` adds an
explicit hard brake on top.

This collapses the previous "balance-while-disarmed" idea — operationally
simpler and aligns with the "disarm during flash" guarantee.

```cpp
const ArmingState::State state = ArmingState::get();

if (state == ArmingState::State::Killed) {
    g_controller->stop();              // brakes wheels, resets balance PIDs
    drive_cmd = { 0.0f, 0.0f, 0.0f };  // for downstream visibility / logging
} else if (state == ArmingState::State::Armed) {
    g_controller->update(drive_cmd, imu_reading, dt);
} else {
    // DISARMED: hard-zero command, skip controller; per-wheel PIDs hold motors.
    drive_cmd = { 0.0f, 0.0f, 0.0f };
    g_drivetrain.drive(drive_cmd);
    // Note: we do NOT call controller.stop() here, so the balance controller
    // retains its internal state. On re-arming, the first update() resets the
    // PIDs via the fault-exit cleanup path if needed.
}
g_drivetrain.update(dt);
```

`ArmingState::begin()` is called in `setup()` before the control task spawns.
Boot default is `DISARMED`.

### OTA composition

`OtaSafeMode::onStart()` calls `ArmingState::disarm()`. From then on, the
control task naturally takes the DISARMED branch and motors are held at
zero throughout the flash window. No separate `OtaSafeMode::isUpdating()`
check is needed in the control task — the safety guarantee comes from the
arming state alone.

If the flash succeeds, the chip reboots and starts again in DISARMED.
If the flash fails and the chip keeps running in degraded mode, it remains
DISARMED until explicit operator action — exactly what we want.
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

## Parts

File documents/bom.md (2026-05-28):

Team SPHERE

# Bill of Materials

### Electronic Components

| Component | Part | Notes | Link | Price (Unit) | Price (Total) |
|---|---|---|---|---|---|
| Microcontroller (body) | ESP32 Wemos D1 R32 / UNO32 | Runs the control loop and the WebSocket server | Course provided | CHF 0.00 | CHF 0.00 |
| Camera (head) | XIAO Vision AI Camera (Seeed Studio) | Streams video from the head | [Digikey](https://www.digikey.ch/de/products/detail/seeed-technology-co-ltd/102010635/26553888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) | CHF 11.77 | CHF 11.77 |
| Motors (×3) | DFRobot FIT0186 | 12 V DC gear motors with encoders, one per omni wheel | [Bastel Garage](https://www.bastelgarage.ch/moteur-a-engrenages-dc-12v-251rpm-18kg-cm-avec-encodeur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) | CHF 35.90 | CHF 107.70 |
| Motor drivers (×3) | L298N H-bridge modules | One channel per motor | Course provided | CHF 7.00 | CHF 21.00 |
| IMU | Adafruit BNO055 | 9-DOF with built-in sensor fusion, I²C address 0x28 | [Bastel Garage](https://www.bastelgarage.ch/bno055-intelligent-9-axis-sensor) | CHF 19.90 | CHF 19.90 |
| Battery | LiPo | 5000mAh / 3S = 11V | Course provided | CHF 32.70 | CHF 32.70 |
| BMS | 3S 60A | Protects the LiPo | Course provided | CHF 15.00 | CHF 15.00 |
| Buck converter | LM2596 (or equivalent) | 12 V → 5 V for the ESP32 | Course provided | CHF 10.90 | CHF 10.90 |
| Servo | SG90 | Changes the angle of the camera | Course provided | CHF 3.00 | CHF 3.00 |
| Head Battery | Li-Ion Battery 3.7V 3200mA NCR18650B 18650 with Flat Top | Battery for servo and camera | [Bastel Garage](https://www.bastelgarage.ch/li-ion-battery-3-7v-3200ma-ncr18650b-18650-with-flat-top) | CHF 8.90 | CHF 8.90 |
| Head Battery shield | 1x18650 Lithium Battery Shield 5V 3A / 3V 1A | To connect the head battery | [Bastel Garage](https://www.bastelgarage.ch/1x18650-lithium-battery-shield-5v-3a-3v-1a) | CHF 9.90 | CHF 9.90 |

### Mechanical parts
| Component | Part | Notes | Link | Price (Unit) | Price (Total) |
|---|---|---|---|---|---|
| Magnets (x6) | Neodymium | (Ø 20 mm, height 5 mm N42) ; hold the head onto the sphere | [Supermagnete](https://www.supermagnete.ch/fre/aimants-disques-neodyme/disque-magnetique-20mm-5mm_S-20-05-N) | CHF 2.00 | CHF 12.00 |
| Balls (14mm diameter) (x6) | Stainless Steel | Balls used in the heads ball bearing | [123Roulement](https://www.123roulement.ch/accessoire/bille-aiguille/bille/ba-14-aisi304) | CHF 3.30 | CHF 19.80 |

---

Reference: https://www.wiki.lesfabriquesduponant.net/index.php?title=Voiture_télécommandée_par_bluetooth

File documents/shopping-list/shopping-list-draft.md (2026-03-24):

Team SPHERE 

# Liste de Composants

## 1. Tête
- Caméra [XIAO VISION AI CAMERA](https://www.digikey.ch/fr/products/detail/seeed-technology-co-ltd/104990982/26834471?productid=26834471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)
- Puce pour caméra  [CV?]
- Puce 2 pour connecter
- Batterie
- Servo
- Aimant(s)
- Roulement à bille  [impression 3D]
- Armature / intérieur  [découpe bois]
- Support caméra mobile  [impression 3D]
- Fils

## 2. Voiture
- 3× Roue omnidirectionnelle  [impression 3D?]
- Armature
- Puce / microcontrôleur  [à déterminer]
- Moteurs × 3
https://www.digikey.ch/fr/products/detail/dfrobot/FIT0185/6588527?productid=6588527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
- Driver x2
https://www.galaxus.ch/fr/s1/product/purecrea-double-bts7960-43a-motor-treiber-h-bruecke-carte-de-developpement-kit-54115890?offerid=8244233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
- 2× Batterie
- Gyroscope  [?]
- Fils

## 3. Boule
- Acheter / imprimer  [système d'attache]

---

Référence: https://www.wiki.lesfabriquesduponant.net/index.php?title=Voiture_t%C3%A9l%C3%A9command%C3%A9e_par_bluetooth

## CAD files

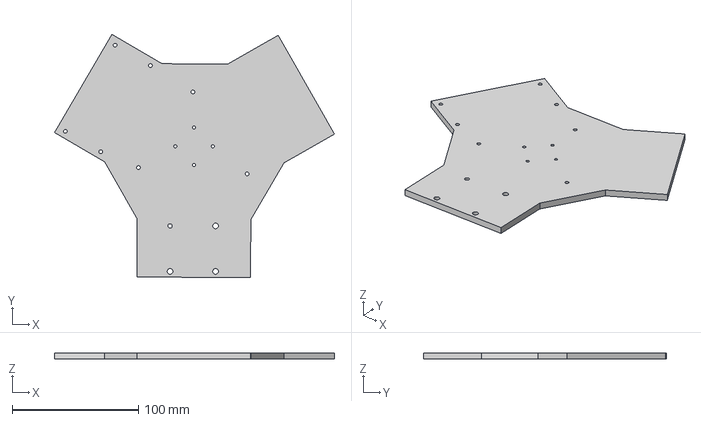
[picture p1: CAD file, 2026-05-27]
README_files/Body/internal Plate (Top).step
221.6 x 192.5 x 5.00 mm

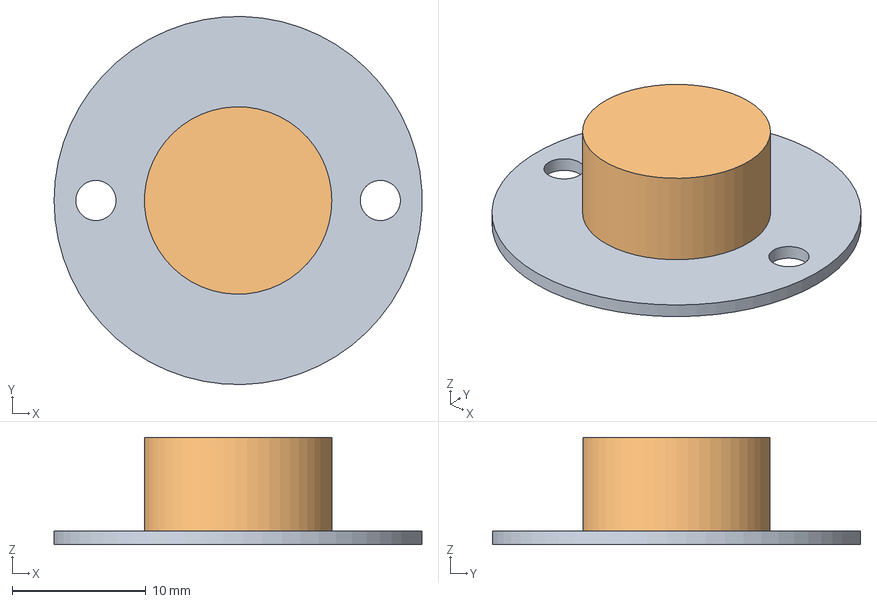
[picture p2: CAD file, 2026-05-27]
README_files/Head-to-sphere contact/Ball Transfer Unit (Support).step
27.5 x 27.5 x 8.00 mm

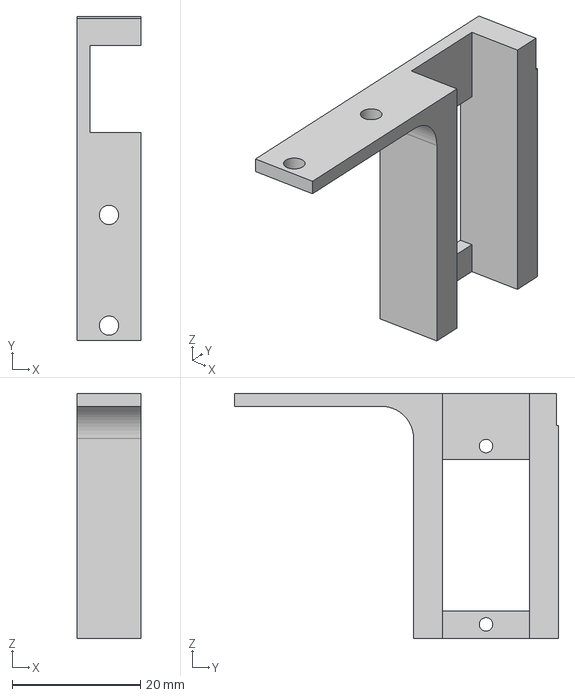
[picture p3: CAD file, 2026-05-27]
README_files/Head/Servo_Holder.step
10.0 x 50.5 x 38.2 mm

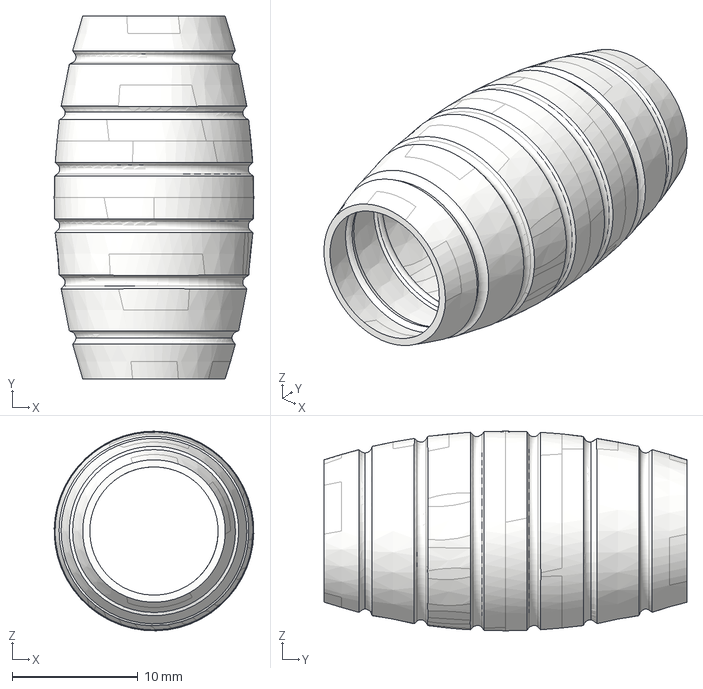
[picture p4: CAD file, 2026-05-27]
README_files/Omniwheel/Small Wheel TPU.step
15.9 x 28.9 x 15.9 mm

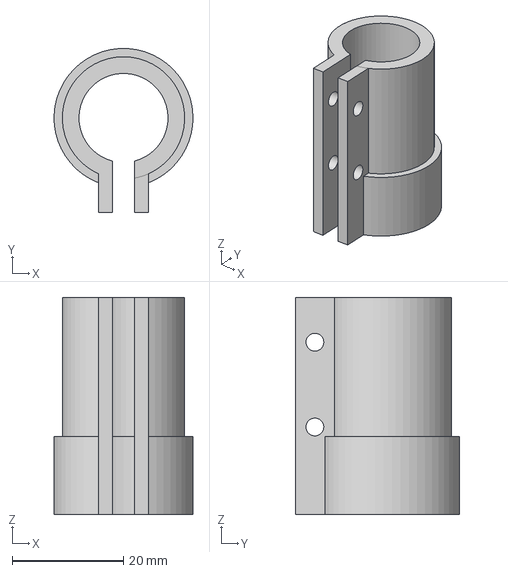
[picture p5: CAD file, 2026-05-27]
README_files/Body/Hose Clamp.step
25.0 x 29.5 x 39.0 mm

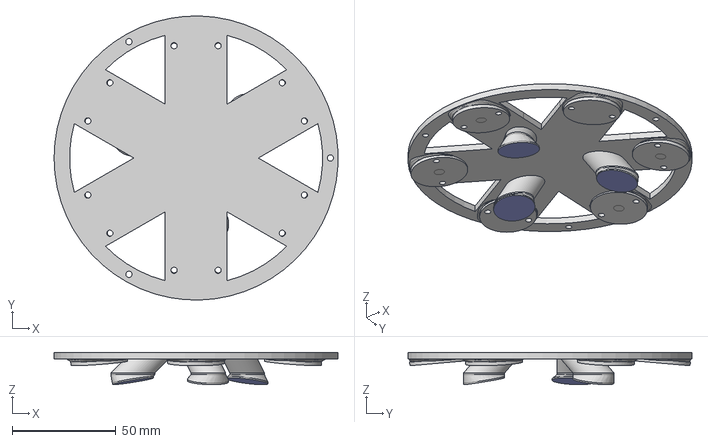
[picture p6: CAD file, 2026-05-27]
README_files/Head-to-sphere contact/Magnet Holder.step
136.9 x 137.0 x 15.6 mm

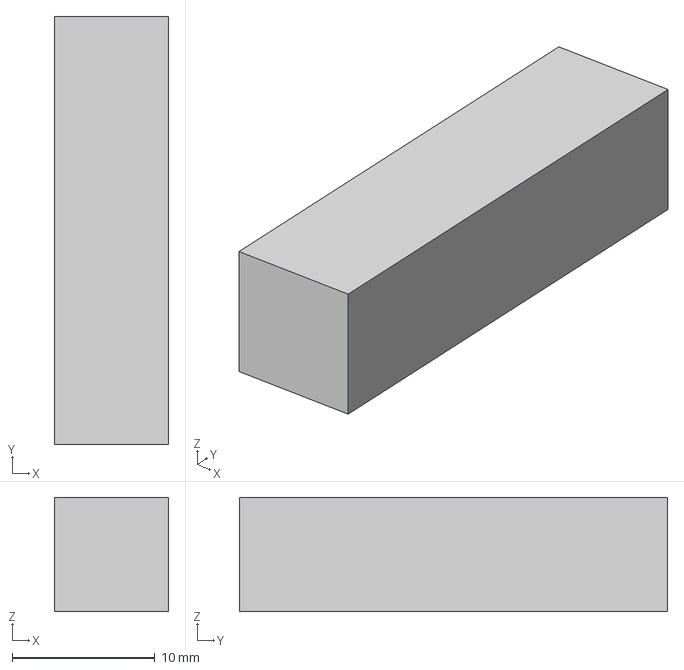
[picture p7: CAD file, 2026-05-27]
README_files/Head/Camera_Holder.step
8.00 x 30.0 x 8.00 mm

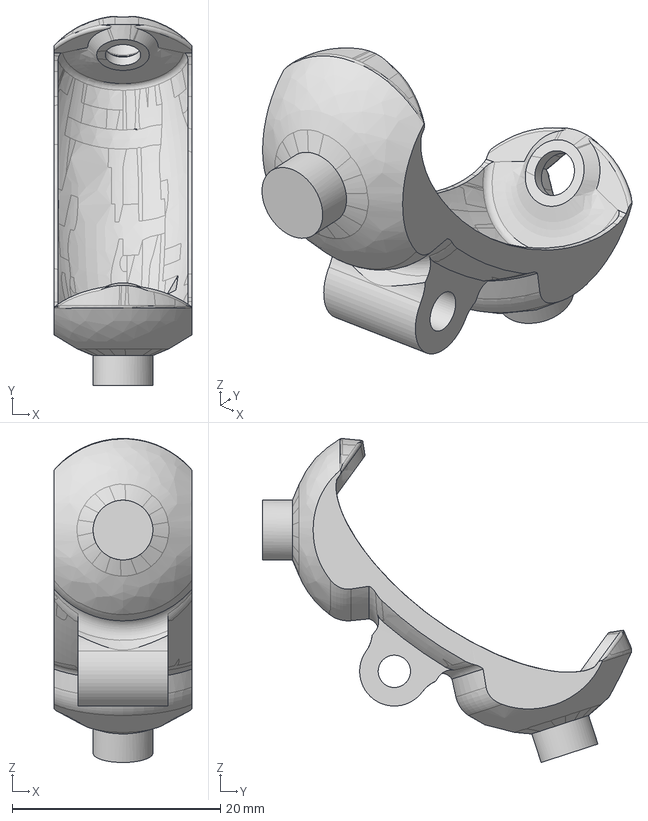
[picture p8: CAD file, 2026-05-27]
README_files/Omniwheel/Holder.step
13.2 x 35.4 x 31.1 mm

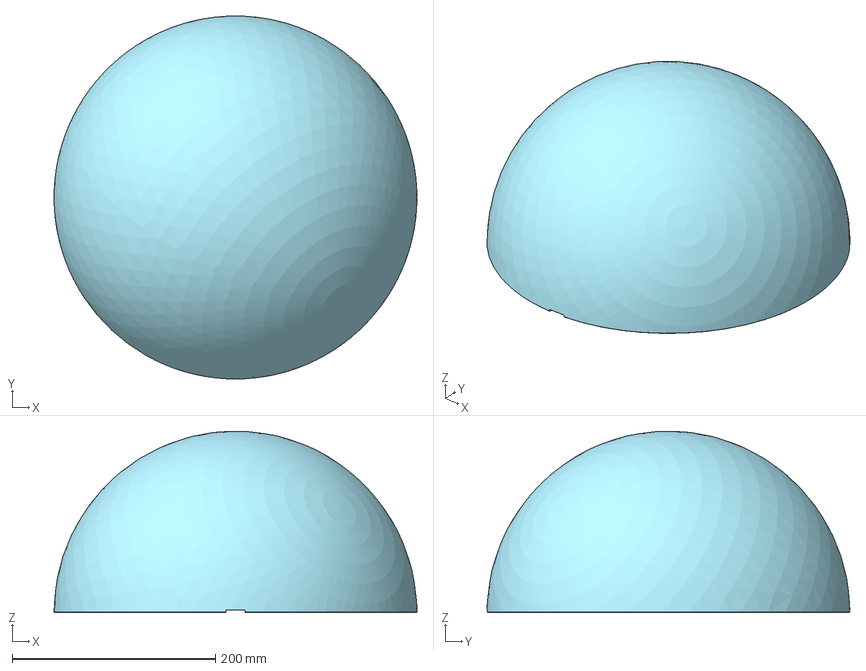
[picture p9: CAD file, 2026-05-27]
README_files/Body/Sphere Shell (Hemisphere).step
357.0 x 356.9 x 178.2 mm

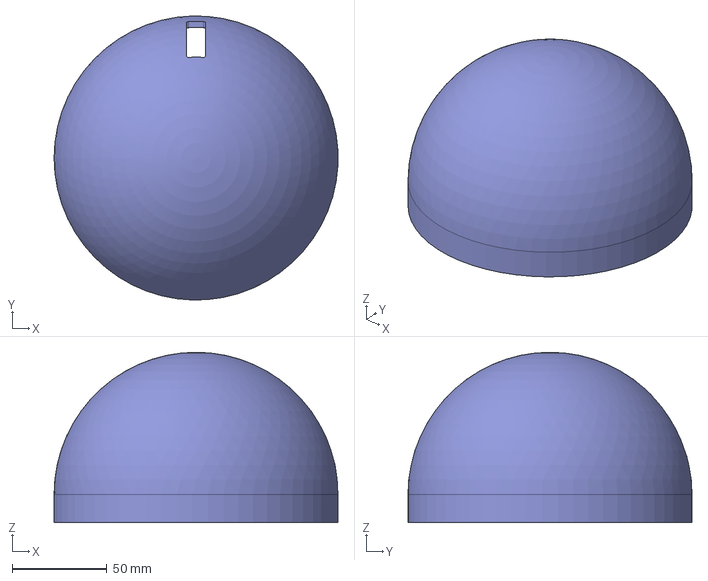
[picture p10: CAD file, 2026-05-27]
README_files/Head/Head Shell.step
149.9 x 149.9 x 90.0 mm

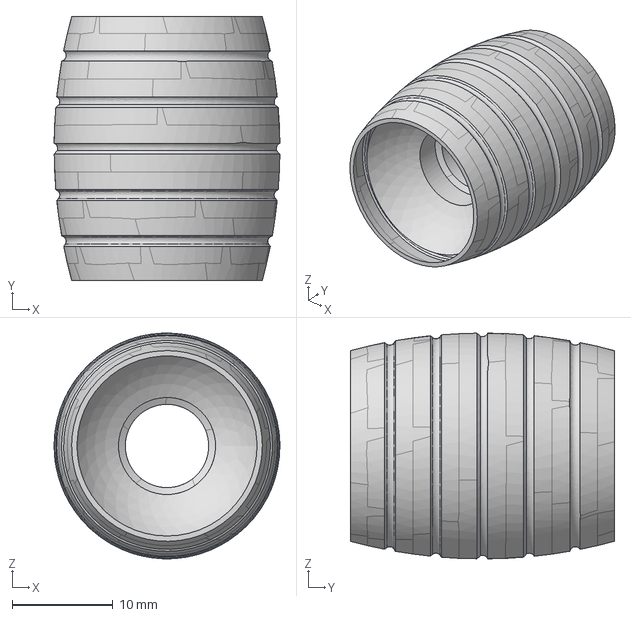
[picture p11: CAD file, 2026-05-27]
README_files/Omniwheel/Big Wheel PETG.step
22.4 x 26.2 x 22.4 mm

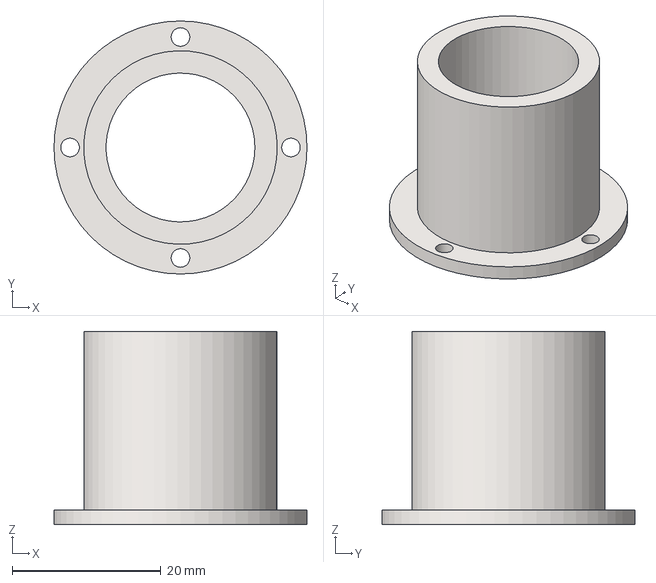
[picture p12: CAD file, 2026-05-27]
README_files/Body/Pipe Holder.step
34.0 x 34.0 x 26.0 mm

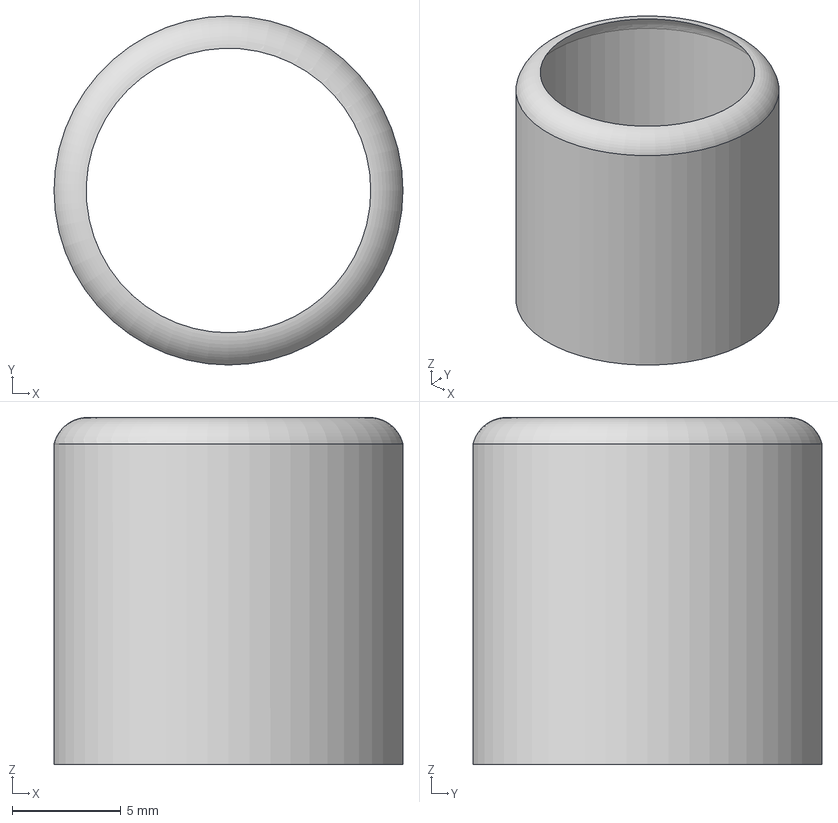
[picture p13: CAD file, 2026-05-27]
README_files/Head-to-sphere contact/Ball Transfer Unit (Tube).step
16.1 x 16.1 x 16.0 mm

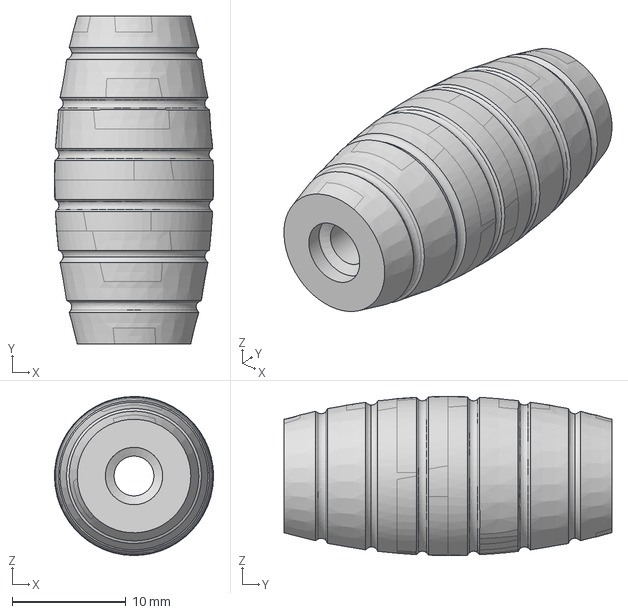
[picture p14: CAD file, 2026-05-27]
README_files/Omniwheel/Small wheel PETG.step
14.0 x 28.9 x 14.0 mm

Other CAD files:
README_files/Body/Magnet Holder.step
README_files/Omniwheel/Big Wheel TPU.step
README_files/Body/Motor holder.step
README_files/Body/BMS Box (Cage).step
README_files/Body/BMS Box (Plate).step
README_files/Body/Internal Plate (Bottom).step
README_files/Body/Internal Plate (Side for LiPo).step
README_files/Body/Internal Plate (Side).step
README_files/Body/Sphere Shell (Rail).step

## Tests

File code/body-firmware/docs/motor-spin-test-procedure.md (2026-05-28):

# Motor + Encoder Test Procedure

## Prerequisites

- PlatformIO CLI installed (`pip install platformio` or via VS Code extension)
- Wemos D1 UNO32 connected via USB
- 12V power supply connected to L298N boards
- EN jumpered HIGH on all three L298N boards

## Wiring

### Motor Driver (L298N)

| Motor | L298N Channel | fwd (IN3) | rev (IN4) |
|---|---|---|---|
| 0 | B | GPIO 14 | GPIO 27 |
| 1 | B | GPIO 16 | GPIO 17 |
| 2 | B | GPIO 18 | GPIO 19 |

Each L298N IN3 pin connects to the corresponding ESP32 GPIO in the "fwd" column.
Each L298N IN4 pin connects to the corresponding ESP32 GPIO in the "rev" column.
L298N GND must be connected to ESP32 GND.

### Encoders

| Motor | Encoder A | Encoder B |
|---|---|---|
| 0 | GPIO 34 | GPIO 35 |
| 1 | GPIO 4 | GPIO 2 |
| 2 | GPIO 39 | GPIO 36 |

Encoder VCC → 3.3V, GND → GND.

## Wheel layout (pull config)

Per `RobotConstants::drivetrainConfig()`:

| Motor | Position | Wheel azimuth |
|---|---|---|
| 0 | back | 180° |
| 1 | front-right | 300° |
| 2 | front-left  |  60° |

## Flashing

### First time (USB)

1. `cd code/body-firmware`
2. Plug in the Wemos D1 UNO32 via USB
3. Run:
   ```
   pio run -e motor_test -t upload
   ```
4. Wait for `SUCCESS` — if it fails with a connection error, hold the BOOT button on the board while it tries to connect, release once upload starts

### Subsequent flashes (OTA, no USB)

`main_motor_test.cpp` uses `OtaSafeMode` with hostname `bb8-robot` (shared across every firmware variant), so once the chip is on WiFi (or reachable via the `bb8-robot-recovery` SoftAP fallback) you can re-flash without a cable:

```
OTA_PASSWORD='your-password' pio run -e motor_test_ota -t upload
```

## Running the test

Pick one console (the test accepts commands on both simultaneously):

- **USB serial:** `pio device monitor -b 115200`
- **Browser (no cable needed):** `http://bb8-robot.local:81/webserial`

You should see:

```
[ota] OtaSafeMode for 'bb8-robot'
[remote-serial] mounted at /webserial on port 81
Motor+encoder test ready.
Layout (pull): 0=back, 1=front-right, 2=front-left
Commands: <motor 0-2> <speed -1.0..1.0> | stop | rpm
```

> Note: motors are explicitly driven to zero PWM in `setup()` (right after `motor.begin()`), so they are guaranteed off until the first command arrives.

## Commands

| Command | Effect |
|---|---|
| `<motor> <speed>` | Set motor (0-2) to speed (-1.0 to 1.0) |
| `stop` | Brake all motors |
| `rpm` | Toggle continuous RPM display (every 20ms) |

## Test 1: Motor 0 (back)

| Step | Send | Expected |
|---|---|---|
| 1 | `0 0.5` | Motor 0 spins forward at half speed |
| 2 | `0 0` | Motor 0 coasts to stop |
| 3 | `0 -0.5` | Motor 0 spins reverse at half speed |
| 4 | `0 0` | Motor 0 coasts to stop |
| 5 | `0 1.0` | Motor 0 spins forward at full speed |
| 6 | `stop` | Motor 0 brakes (stops faster than coast) |

**Result:** PASS / FAIL
**Notes:**

## Test 2: Motor 1 (front-right)

| Step | Send | Expected |
|---|---|---|
| 1 | `1 0.5` | Motor 1 spins forward at half speed |
| 2 | `1 0` | Motor 1 coasts to stop |
| 3 | `1 -0.5` | Motor 1 spins reverse at half speed |
| 4 | `1 0` | Motor 1 coasts to stop |
| 5 | `1 1.0` | Motor 1 spins forward at full speed |
| 6 | `stop` | Motor 1 brakes (stops faster than coast) |

**Result:** PASS / FAIL
**Notes:**

## Test 3: Motor 2 (front-left)

| Step | Send | Expected |
|---|---|---|
| 1 | `2 0.5` | Motor 2 spins forward at half speed |
| 2 | `2 0` | Motor 2 coasts to stop |
| 3 | `2 -0.5` | Motor 2 spins reverse at half speed |
| 4 | `2 0` | Motor 2 coasts to stop |
| 5 | `2 1.0` | Motor 2 spins forward at full speed |
| 6 | `stop` | Motor 2 brakes (stops faster than coast) |

**Result:** PASS / FAIL
**Notes:**: inverted direction

## Test 4: Encoder 0 (back)

| Step | Send | Expected |
|---|---|---|
| 1 | `rpm` | RPM display turns ON |
| 2 | `0 0.5` | RPM for [0] shows positive value (~100-125 RPM) |
| 3 | `0 -0.5` | RPM for [0] shows negative value |
| 4 | `0 1.0` | RPM for [0] increases (~200-250 RPM) |
| 5 | `stop` | RPM for [0] drops to ~0 |

**Result:** PASS / FAIL
**Notes:** 0 +-0.5 -> +.10rpm

## Test 5: Encoder 1 (front-right)

| Step | Send | Expected |
|---|---|---|
| 1 | `1 0.5` | RPM for [1] shows positive value (~100-125 RPM) |
| 2 | `1 -0.5` | RPM for [1] shows negative value |
| 3 | `1 1.0` | RPM for [1] increases (~200-250 RPM) |
| 4 | `stop` | RPM for [1] drops to ~0 |

**Result:** PASS / FAIL
**Notes:**

## Test 6: Encoder 2 (front-left)

| Step | Send | Expected |
|---|---|---|
| 1 | `2 0.5` | RPM for [2] shows positive value (~100-125 RPM) |
| 2 | `2 -0.5` | RPM for [2] shows negative value |
| 3 | `2 1.0` | RPM for [2] increases (~200-250 RPM) |
| 4 | `stop` | RPM for [2] drops to ~0 |
| 5 | `rpm` | RPM display turns OFF |

**Result:** PASS / FAIL
**Notes:**

## Troubleshooting

| Symptom | Likely Cause |
|---|---|
| Motor doesn't spin at all | Check wiring to L298N IN3/IN4 and power supply |
| Motor spins but direction is swapped | Swap fwd/rev pin values in `src/config/pins.h` |
| Motor 1 behaves erratically | GPIO 16/17 conflict with PSRAM (only on WROVER modules, not WROOM) |
| Serial shows nothing | Confirm baud rate is 115200, check USB connection |
| Motor spins at full speed regardless of value | EN pin not jumpered HIGH, or IN pins wired to EN |
| Upload fails with connection error | Hold BOOT button on board during upload |
| RPM shows 0 while motor spins | Encoder A/B wires swapped or disconnected |
| RPM sign is opposite to expected | Swap encoder A and B pins in `src/config/pins.h` |
| RPM is very noisy | Check encoder connections, ensure 3.3V power to encoder |

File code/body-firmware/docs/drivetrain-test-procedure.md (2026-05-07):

# Drivetrain Test Procedure

## Prerequisites

- Motor spin test passing (see `motor-spin-test-procedure.md`)
- All three motors spinning in correct directions with correct RPM readings
- Robot on blocks (wheels off the ground) or in a clear area

## Flashing

```
cd code/body-firmware
pio run -e drivetrain_test -t upload
```

## Serial Monitor

```
pio device monitor -b 115200
```

## Commands

| Command | Effect |
|---|---|
| `<vx> <vy> <omega_deg>` | Drive at body velocity (m/s, m/s, deg/s) |
| `stop` | Brake all motors |
| `rpm` | Toggle target vs actual RPM display (T = target, A = actual) |

## Convention

- vx positive = forward
- vy positive = left
- omega positive = CCW from above
- Motor 0 at 0°, Motor 1 at 120°, Motor 2 at 240°

## Test 1: Pure Rotation (CW)

| Step | Send | Expected |
|---|---|---|
| 1 | `rpm` | RPM display turns ON |
| 2 | `0 0 -90` | Robot rotates CW, all wheels spin at equal RPM |
| 3 | Observe | Target RPMs are all equal and same sign |
| 4 | Observe | Actual RPMs converge to targets within ~1s |
| 5 | `stop` | All motors brake |

**Result:** PASS / FAIL
**Notes:**

## Test 2: Pure Rotation (CCW)

| Step | Send | Expected |
|---|---|---|
| 1 | `0 0 90` | Robot rotates CCW, all wheels spin (opposite sign to Test 1) |
| 2 | Observe | Actual RPMs converge to targets |
| 3 | `stop` | All motors brake |

**Result:** PASS / FAIL
**Notes:**

## Test 3: Forward (vx only)

| Step | Send | Expected |
|---|---|---|
| 1 | `0.1 0 0` | Robot moves forward |
| 2 | Observe | Motor 0 target ≈ 0, Motors 1 & 2 equal magnitude opposite sign |
| 3 | Observe | Actual RPMs converge to targets |
| 4 | `stop` | All motors brake |

**Result:** PASS / FAIL
**Notes:**

## Test 4: Backward (vx only)

| Step | Send | Expected |
|---|---|---|
| 1 | `-0.1 0 0` | Robot moves backward |
| 2 | Observe | Same pattern as Test 3 but signs flipped |
| 3 | `stop` | All motors brake |

**Result:** PASS / FAIL
**Notes:**

## Test 5: Strafe Left (vy only)

| Step | Send | Expected |
|---|---|---|
| 1 | `0 0.1 0` | Robot moves left |
| 2 | Observe | Motor 0 has largest magnitude, Motors 1 & 2 share remainder |
| 3 | `stop` | All motors brake |

**Result:** PASS / FAIL
**Notes:**

## Test 6: Strafe Right (vy only)

| Step | Send | Expected |
|---|---|---|
| 1 | `0 -0.1 0` | Robot moves right |
| 2 | Observe | Same pattern as Test 5 but signs flipped |
| 3 | `stop` | All motors brake |

**Result:** PASS / FAIL
**Notes:**

## Test 7: Combined Motion

| Step | Send | Expected |
|---|---|---|
| 1 | `0.1 0 45` | Robot moves forward while rotating CCW |
| 2 | Observe | Actual RPMs converge to targets |
| 3 | `stop` | All motors brake |

**Result:** PASS / FAIL
**Notes:**

## Test 8: PID Tracking Quality

| Step | Send | Expected |
|---|---|---|
| 1 | `0 0 -90` | Steady rotation |
| 2 | Wait 3s | Actual RPMs settle within ±5% of targets |
| 3 | `0 0 -180` | Step change — RPMs increase |
| 4 | Observe | Actual RPMs converge without excessive overshoot |
| 5 | `stop` | All motors brake |

**Result:** PASS / FAIL
**Notes:**

## Troubleshooting

| Symptom | Likely Cause |
|---|---|
| Robot drifts instead of pure rotation | One motor wired backwards — recheck pin swap |
| Target RPMs look right but actuals don't converge | PID gains need tuning (Kp=1.0, Ki=0.1, Kd=0.01) |
| Robot moves in wrong direction | Motor numbering doesn't match 0°/120°/240° layout |
| Oscillation / buzzing | Kp too high or Kd too low |
| Slow response | Kp too low or Ki too low |

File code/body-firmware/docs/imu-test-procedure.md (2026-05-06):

# BNO055 IMU Test Procedure

## Prerequisites

- PlatformIO CLI installed
- Wemos D1 UNO32 connected via USB (data cable)
- BNO055 breakout board wired via I2C

## Wiring

| BNO055 Pin | ESP32 Pin |
|---|---|
| VIN | 3.3V |
| GND | GND |
| SDA | GPIO 26 |
| SCL | GPIO 25 |

I2C address: 0x28 (default, ADR pin LOW).

## Flashing

1. `cd code/body-firmware`
2. Plug in the Wemos D1 UNO32 via USB
3. Run:
   ```
   pio run -e wemos_d1_uno32 -t upload
   ```
4. If upload fails with connection error, hold BOOT button during upload

## Running the Test

1. Open serial monitor:
   ```
   pio device monitor -b 115200
   ```
2. Confirm you see:
   ```
   BNO055 IMU test — initializing...
   BNO055 ready. Commands: all, euler, quat, gyro, cal, accel
   ```
3. If you see `ERR: BNO055 not detected`, check I2C wiring

## Commands

| Command | Output |
|---|---|
| `euler` | Heading, roll, pitch (degrees) |
| `quat`  | Quaternion (w, x, y, z) |
| `gyro`  | Gyroscope (deg/s) |
| `accel` | Linear acceleration (m/s²) |
| `cal` | Calibration status (0-3 per subsystem) |
| `all` | All of the above |

Default display on boot: euler + calibration.

## Test 1: Sensor Detection

| Step | Action | Expected |
|---|---|---|
| 1 | Power on, open serial monitor | `BNO055 ready.` message appears |
| 2 | If error, swap SDA/SCL wires and reset | Sensor detected on retry |

**Result:** PASS / FAIL
**Notes:**

## Test 2: Calibration

| Step | Action | Expected |
|---|---|---|
| 1 | Send `cal` | Calibration values stream (sys, gyro, accel, mag) |
| 2 | Leave board still on flat surface for 5s | Gyro calibration reaches 3 |
| 3 | Tilt board slowly in multiple directions | Accel calibration reaches 3 |
| 4 | Move board in figure-8 pattern | Mag calibration reaches 3 |
| 5 | Wait until sys=3 | All subsystems calibrated |

**Result:** PASS / FAIL
**Notes:**

## Test 3: Euler Angles

| Step | Action | Expected |
|---|---|---|
| 1 | Send `euler` | Euler angles stream (heading, roll, pitch) |
| 2 | Place board flat | Roll and pitch near 0 |
| 3 | Rotate board on table (yaw) | Heading changes 0–360 |
| 4 | Tilt board forward | Pitch changes |
| 5 | Tilt board sideways | Roll changes |
| 6 | Return to flat | Roll and pitch return near 0 |

**Result:** PASS / FAIL
**Notes:**

## Test 4: Quaternion

| Step | Action | Expected |
|---|---|---|
| 1 | Send `quat` | Quaternion values stream (w, x, y, z) |
| 2 | Hold board still | Values stable, w near 1.0, others near 0 (if upright) |
| 3 | Rotate board slowly | Values change smoothly, no jumps |

**Result:** PASS / FAIL
**Notes:**

## Test 5: Gyroscope

| Step | Action | Expected |
|---|---|---|
| 1 | Send `gyro` | Gyro values stream (x, y, z in deg/s) |
| 2 | Hold board still | All values near 0 |
| 3 | Rotate board around one axis | Corresponding axis shows non-zero reading |
| 4 | Stop rotating | Values return near 0 |

**Result:** PASS / FAIL
**Notes:**

## Test 6: Linear Acceleration

| Step | Action | Expected |
|---|---|---|
| 1 | Send `accel` | Acceleration values stream (x, y, z in m/s²) |
| 2 | Hold board still | All values near 0 (gravity is subtracted) |
| 3 | Shake board along one axis | Corresponding axis shows spikes |
| 4 | Hold still again | Values return near 0 |

**Result:** PASS / FAIL
**Notes:**

## Test 7: Calibration Persistence

| Step | Action | Expected |
|---|---|---|
| 1 | Calibrate fully (sys=3) | Offsets auto-saved to NVS |
| 2 | Reset board (press reset button) | Board restarts |
| 3 | Send `cal` | Calibration values recover faster than first boot |

**Result:** PASS / FAIL
**Notes:**

## Troubleshooting

| Symptom | Likely Cause |
|---|---|
| `ERR: BNO055 not detected` | SDA/SCL swapped, not connected, or wrong I2C address |
| Readings are all zeros | `read()` called before `begin()` succeeded |
| Heading drifts over time | Magnetometer not calibrated (do figure-8 motion) |
| Euler angles jump at 0/360 boundary | Normal gimbal behavior near singularities |
| Calibration doesn't persist after reset | NVS storage issue — check Preferences library |
| Values update slowly | Check that delay in loop is 100ms, not higher |

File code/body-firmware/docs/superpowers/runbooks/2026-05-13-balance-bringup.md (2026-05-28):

# Balancing drivetrain controller — bench bring-up runbook

**Date:** 2026-05-13
**Audience:** operator on the bench during first power-on of the balancing controller.

This runbook is the operator's reference during bench bring-up. It is kept
separate from the design spec
(`docs/superpowers/specs/2026-05-13-balancing-drivetrain-controller-design.md`)
so that bench notes, gotchas, and field-tuned values can be appended here as
they accumulate without churning the design document. Update freely.

The harness used throughout is `main_balance_test` (PlatformIO env
`balance_test`). All `balance ...` commands below are sent over RemoteSerial.

---

## 1. Bench-verification sequence

Run `main_balance_test`. Observe Serial / RemoteSerial output. Execute in
order:

1. `arm`. Place robot on soft surface.
2. Hand-tilt platform forward 10° → wheels drive backward to restore level.
3. Hand-tilt platform left 10° → wheels drive right.
4. `cmd 0.5 0 0` → platform tilts forward; sphere rolls forward.
5. `cmd 0 0 0` → platform returns to level; sphere decelerates.
6. Tilt past 60° → drive halts; fault transition logs. Return below 55° →
   drive resumes.
7. `kill` → drive halts immediately. State = Killed.
8. `clearkill` then `arm` → drive resumes.

If any step fails, jump to the [Axis diagnosis](#3-axis-diagnosis) section
before re-tuning gains.

---

## 2. Sign-convention check (`gyroPitchSign` / `gyroRollSign`)

`gyroPitchSign` and `gyroRollSign` default to `+1` in `BalanceConfig` and are
verified at bring-up with the following sub-procedure. Both signs are
configurable via RemoteSerial without reflash if bring-up reveals an inverted
axis.

1. Place platform level. Confirm `gx ≈ 0`, `gy ≈ 0`, `gz ≈ -1`.
2. Tilt platform forward slowly. Confirm `pitch_actual` increases monotonically
   and `imu.gyro.y` is non-zero with consistent sign during the tilt.
3. Numerically integrate `imu.gyro.y` over the motion and compare to the change
   in `pitch_actual`. If they have opposite signs, set
   `gyroPitchSign = -1` via:

   ```
   balance set gyroPitchSign -1.0
   balance save
   ```

4. Repeat steps 2–3 for roll, using `imu.gyro.x` and `gyroRollSign`.

The signs live as `float` knobs in `BalanceConfig`, so a flip is live and
persistent (after `balance save`) — no reflash needed.

---

## 3. Axis diagnosis

> Tilt the platform forward by hand and watch the wheels.
>
> - **Wheels drive in the wrong direction on forward tilt** (sign-inverted
>   axis) → set `gyroPitchSign = -1.0` via
>   `balance set gyroPitchSign -1.0`. Live, no reflash.
> - **Wheels drive *sideways* on forward tilt** (rotated mount: chip-Y points
>   along body-X, etc.) → the two `BalanceConfig` sign knobs cannot fix this.
>   Either physically remount the BNO055 so chip-X aligns with body-forward,
>   or call `_bno.setAxisRemap(...)` in `BNO055IMU::begin()` and reflash.
>   Re-run the bring-up procedure after.
>
> Repeat the diagnosis for roll on body-X.

The distinction matters: the two `BalanceConfig` sign knobs are
one-dimensional; they cannot rotate a coordinate frame. If chip and body axes
are *rotated* relative to each other (not just sign-inverted), the fix is
mechanical or in IMU driver setup — not in `BalanceConfig`.

---

## 4. Tuning guide

### Procedure (do in order)

1. **P only.** Ki = Kd = 0. Robot on soft surface. Increase `pitchKp` (and
   matching `rollKp`) until restoring action is clear, with light overshoot.
2. **Add D.** Increase `pitchKd` until overshoot is damped without
   high-frequency wobble. (Wobble = D too high, amplifying gyro noise.)
3. **Iterate P/D.** With damping, P can usually go higher. Repeat 1–2.
4. **I, sparingly.** Only if the robot settles slightly off-vertical. Start at
   ~5 % of Kp; increase only if needed.
5. **`tiltPerVelocity` last.** Subjective: full stick = full attack
   acceleration without exceeding `maxTiltSetpoint`. Tune by feel.

### Symptoms → adjustments

| Observation | Likely cause | Adjust |
| --- | --- | --- |
| Mushy / slow response to commands | Kp too low | ↑ `pitchKp` / `rollKp` |
| Slow oscillation (~1–2 Hz) around upright | Kp too high or Kd too low | ↓ Kp or ↑ Kd |
| High-frequency motor buzz | Kd too high (amplifying gyro noise) | ↓ Kd |
| Persistent off-vertical lean (steady-state error) | Ki too low | ↑ Ki (start at ~5% of Kp) |
| Drifts away over time / wind-up | Ki too high or anti-windup not engaging | ↓ Ki; verify anti-windup integral clamp |
| Weak feel even at full stick | `tiltPerVelocity` low, or output clamping | ↑ `tiltPerVelocity`; check `maxOutputVelocity`  |
| Alarming lean on full stick | `maxTiltSetpoint` too high | ↓ `maxTiltSetpoint` |
| Fault trips during normal aggressive driving | Envelope too tight (or real problem) | First check the physics — shouldn't see 60° normally. If real, ↑ `envelopeEnterSin` slightly. |
| Fault chatters at the edge | Hysteresis gap too small | Widen the gap between enter and exit |
| Kick when recovering from fault | Balance PIDs not reset on entry | Bug — verify enterFault() calls pid.reset() |
| Drifts sideways while driving forward | Pitch/roll PID asymmetry, or mechanical | Try `rollKp` ≠ `pitchKp` slightly; if persists, suspect hardware |

---

## 5. Persistence smoke test

Confirm NVS-backed `BalanceConfig` round-trips through a reboot:

```
balance set pitchKp 2.0
balance save
# power-cycle the board (or trigger a software reset)
balance show pids
```

**Assert:** `pitchKp == 2.0` in the `balance show pids` output. If the value
reverts to the default, NVS save/load is broken — do not proceed with bench
verification.

---

## 6. Configuration footgun list

- **`maxTiltSetpoint` must stay strictly below `asin(envelopeEnterSin)`.** The
  setpoint must never command a tilt that would itself trip the fault
  envelope. The tuner enforces this invariant on every `balance set`. If the
  operator sees a `rejected` message on a `set` command, this is almost
  certainly the invariant they violated — either lower `maxTiltSetpoint`, or
  raise `envelopeEnterSin` first and then retry the `maxTiltSetpoint` change.
- The envelope hysteresis pair must satisfy
  `envelopeExitSin < envelopeEnterSin`. The tuner rejects updates that would
  invert the gap. Widen the gap if the fault chatters at the edge.
- All PID gains (`pitchKp`, `pitchKi`, `pitchKd`, `rollKp`, `rollKi`,
  `rollKd`) must be `≥ 0`. Negative values are rejected — sign convention is
  expressed exclusively through `gyroPitchSign` / `gyroRollSign`.

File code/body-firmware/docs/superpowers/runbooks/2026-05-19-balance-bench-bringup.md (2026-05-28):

# Balance Bench Bring-Up — 2026-05-19

End-to-end bench protocol covering OTA verification, sign-direction tilt check, arming-state cycle, re-arm windup, and fault envelope. Five gating phases — do not progress to phase N+1 until phase N has all "Expected"s matched.

Each step shows **Expected** behavior and an **Observed** blank for the operator to fill in.

---

## Rollback prologue (do this BEFORE Phase A)

Before flashing this branch:

1. **Record the SHA currently on the robot.** Read it from the boot banner of the previous flash, or note whatever was last uploaded (`git log -1` on the previously-deployed branch). Write it here:

   - Previously-deployed SHA: `[                                ]`

2. **Confirm the safe-mode SoftAP is reachable** from your laptop. The firmware's `BringUp` module spins up SoftAP `bb8-robot-recovery` whenever WiFi-STA association fails. Hold the chip's reset button for 5 s to force that path; your laptop must see SSID `bb8-robot-recovery` in the network list. If the new firmware misbehaves on bench, this is the recovery path:

   ```sh
   git checkout <previous-sha>
   pio run -e robot_ota -t upload
   ```

   - SoftAP visible from laptop: `[   ]`

If either prerequisite fails, fix it before flashing — do not proceed without a rollback option.

---

## Phase A — power-on + comms verification (~1–2 min)

**Use the full WebSerial endpoint at `http://bb8-robot.local:81/webserial`, NOT WebSerial Lite.** Lite re-emits buffered input on reconnect, which surfaces as duplicate `ok:` lines from the balance tuner and spurious `error: unknown balance verb` errors during Phase B.

Logging note: `ArmingState` is the single source of truth for transition logs. A successful transition prints exactly one line, formatted `[arming] -> <State>`. Re-issuing the same verb (e.g. `arm` while already Armed) is a FSM no-op and prints nothing — use `armstate` to query.

IMU note: BNO055 runs in **IMUPLUS** mode (gyro + accel fusion, no magnetometer). `isFullyCalibrated()` only checks `gyro==3 && accel==3` — `sys` and `mag` stay at 0 forever and that's expected (the `[cal]` lines still print all four, ignore the last two). Cold-boot expectation: hold chip still (gyro→3 in ~2s), then place on each of 6 cube faces ~10s each (accel→3, ~60s total). Once `[cal] fully calibrated — offsets saved` appears, offsets are persisted to NVS and every subsequent boot fast-paths to `[cal] warm boot — gyro settled, ready` within ~1s. Wipe NVS or swap chips → cold boot again.

| # | Action | Expected | Observed |
|---|---|---|---|
| 1 | `pio run -e robot_ota -t upload` | Console: `BB-8 main_robot starting.` and `[arming] boot state: Disarmed` | `[ ]` |
| 2 | Open WebSerial at `http://bb8-robot.local:81/webserial`; send `armstate` | `[arming] Disarmed` | `[ ]` |
| 3 | While WebSerial is still connected, kick a second OTA upload | `[ota] update starting` and `[arming] -> Disarmed` (only if currently Armed; silent no-op otherwise — both confirm the OTA→disarm hook fired) | `[ ]` |
| 4a | Send `arm` | `[arming] -> Armed` | `[ ]` |
| 4b | Send `kill` | `[arming] -> Killed` | `[ ]` |
| 4c | Send `clearkill` | `[arming] clearKill -> Disarmed` | `[ ]` |
| 4d | Send `arm` | `[arming] -> Armed` | `[ ]` |
| 4e | Send `disarm` | `[arming] -> Disarmed` | `[ ]` |

Gate: do not proceed unless every Observed matches Expected.

---

## Phase B — sign-direction check (robot OFF the ground, wheels free)

Purpose: bench data that resolves **B1** (balance controller sign question — three independent analyses disagreed). Defer the controller change until this phase produces a recorded observation.

Setup:

```
balance set pitchKp 0.05
balance set pitchKi 0
balance set pitchKd 0
balance set rollKp 0
balance set rollKi 0
balance set rollKd 0
balance save
arm
```

| # | Action | Expected (decision matrix) | Observed |
|---|---|---|---|
| 1 | Tilt platform front-down / back-up by hand | Wheels roll shell **BACKWARD** → current sign matches sphere/BB-8 spec, **no flip needed**. Wheels roll shell **FORWARD** → Segway model, **flip pitchKp**. | `[ ]` |
| 2 | Tilt left-side-down | Shell rolls to the **RIGHT** → correct sign (sphere). Shell rolls to the **LEFT** → **flip rollKp**. | `[ ]` |
| 3 | `disarm` | `[arming] -> Disarmed` | `[ ]` |

Record the decision (no flip / flip pitch / flip roll / flip both) in the **Findings** section at the bottom — that data feeds the follow-up B1 PR.

---

## Phase C — turn/strafe convention (`drivetrain_test` env)

Purpose: bench data that resolves **B7** (kinematics L/R question). The teleop pages, firmware kinematics, and IMU all agree on `+vy = LEFT, +ω = CCW` REP-103 on paper; physical observation needed.

```
pio run -e drivetrain_test_ota -t upload
```

Connect WebSerial. Each row sends a body-frame velocity command `vx vy omega`.

| # | Command | Expected (REP-103) | Observed |
|---|---|---|---|
| 1 | `0.3 0 0` | Shell rolls **forward** | **2026-05-19**: rolled **BACKWARD** — pre-fix vx sign was inverted. **Fixed in OmniKinematics.h (vx coefficient `-sin` → `+sin`).** Re-verify after re-flash. |
| 2 | `0 0.3 0` | Shell strafes **LEFT** | **2026-05-19**: strafed LEFT — correct. |
| 3 | `0 0 30`  | Shell yaws **LEFT (CCW from above)** | **2026-05-19**: yawed CCW — correct. |
| 4 | `stop` | Wheels brake | `[ ]` |

Record any further disagreements in the **Findings** section — they feed the follow-up B7 PR. Re-flashing after the vx fix is required before Phase D/E continue.

---

## Phase D — re-arm windup verification (`robot_ota` env)

**REQUIRED**: robot **ON THE GROUND** (or under wheel load — e.g. shell mass on the platform). Windup-jolt (B3) is invisible on free-spinning wheels.

Note: the producer-silence auto-disarm backstop (B4) has been **removed**. Armed state now persists until an explicit `disarm`, `kill`, OTA upload, or fault-envelope trip. Short-term silence (<200ms) still ramps drive_cmd to zero via `STALENESS_TIMEOUT_MS`, but the controller stays armed and the wheels hold-zero rather than auto-disarming. If the operator closes the producer tab while armed, the robot remains armed — explicit safety responsibility is on the operator (or the kill switch).

```
pio run -e robot_ota -t upload
```

| # | Action | Expected | Observed |
|---|---|---|---|
| 1 (**B3 verification — robot ON GROUND**) | Open webapp `/control`, connect, click **Arm**, send forward velocity (hold `W`) for ~1 s, click **Disarm**, **immediately** click **Arm** again, send zero velocity (no keys). | Wheels do **NOT** jolt on re-arm — PID integrators were reset on disarm edge. Pre-fix the accumulated I-term would slam wheels on re-arm. | `[ ]` |
| 2 | Arm via WebSerial, wait 10+ seconds without sending any velocity. Send `armstate`. | `[arming] Armed` (no auto-disarm — backstop is gone). | `[ ]` |

Gate: B3 is the safety-critical fix shipping in this PR. Must observably match Expected before moving on.

---

## Phase E — fault envelope (robot on the ground or in a cradle)

Setup:

```
balance reset
balance save
arm
```

| # | Action | Expected | Observed |
|---|---|---|---|
| 1 | Manually tilt past 60° (enter envelope) | Wheels stop: `_drivetrain.drive({0, 0, 0})`, fault latched | `[ ]` |
| 2 | Return below 55° (exit envelope, Schmitt hysteresis) | Wheels resume balancing | `[ ]` |
| 3 | `disarm` | `[arming] -> Disarmed` | `[ ]` |

---

## Phase F — yaw + heading hold (robot on the ground or in a cradle)

This phase brings up the cascaded yaw controller and the heading-hold outer loop. Run after Phase E. Both loops are off-by-default in firmware shipped before Commit 3 (`yawRateKp=0`, `headingKp=0`); from Commit 4 onward `headingKp=1.0` is the compiled default but `yawRateKp` is still zero — without a non-zero `yawRateKp` the inner PID is bypassed and the outer loop is moot.

Setup:

```
balance reset
balance save
arm
```

### Phase F1 — yaw-rate sign sanity (cradle, wheels free)

| # | Action | Expected | Observed |
|---|---|---|---|
| 1 | `balance set yawRateKp 0.5` | `ok: yawRateKp=0.5` | `[ ]` |
| 2 | Manually spin the chassis CCW (looking from above) | Wheels drive opposite (CW) to null the spin | `[ ]` |
| 3 | Manually spin CW | Wheels drive CCW | `[ ]` |
| 4 | If wheels reinforce the spin (positive feedback): `balance set gyroYawSign -1` | `ok: gyroYawSign=-1` | `[ ]` |
| 5 | Repeat steps 2–3; confirm corrective behavior | Wheels counteract spin | `[ ]` |

### Phase F2 — yaw-rate gain tuning

**Before tuning `yawRateKp`**, disable the outer heading-hold loop: `balance set headingKp 0`. Otherwise the moment you arm with a non-zero `yawRateKp`, the outer loop engages and your rate-loop response will be polluted by heading-correction transients. Restore `headingKp = 1.0` after Phase F2 is satisfied.

| # | Action | Expected | Observed |
|---|---|---|---|
| 1 | Operator stick at zero, gently perturb yaw by hand | Crisp recentering with no oscillation | `[ ]` |
| 2 | If oscillating, lower `yawRateKp` 20%; if sluggish, raise 20% | Settling within ~0.5 s | `[ ]` |
| 3 | If steady-state heading drift visible, `balance set yawRateKi 0.1` and re-perturb | Drift eliminated, no slow oscillation | `[ ]` |
| 4 | `balance save` | `ok: saved` | `[ ]` |

### Phase F3 — heading hold (stick centered)

**Restore `headingKp = 1.0` before this phase** (`balance set headingKp 1.0`) if you disabled it for Phase F2.

| # | Action | Expected | Observed |
|---|---|---|---|
| 1 | Confirm `headingKp` non-zero (default `1.0`); leave stick centered | Bot holds heading; push by hand → wheels return to original yaw | `[ ]` |
| 2 | Stick to non-zero omega for 2 s, release | Bot turns under stick; on release, holds the **new** heading (no snap-back to pre-stick yaw) | `[ ]` |
| 3 | Repeat 5× re-latch cycles | No drift, no oscillation between cycles | `[ ]` |
| 4 | Try arming while shaking the chassis (gyro loud) | `arm` is **refused**; `kEvent_PREARM_REJECTED` fires in telemetry | `[ ]` |
| 5 | Hold still 500 ms; send `arm` | `[arming] -> Armed`; heading hold engages from tick 1 | `[ ]` |
| 6 | If hold is too aggressive or oscillating, lower `headingKp` 20%; if drift accumulates, raise 20% | Bot holds at rest within ±2° over 30 s | `[ ]` |
| 7 | `balance save` | `ok: saved` | `[ ]` |

---

## Findings

Use this section to record the bench observations that resolve the deferred questions. The data here directly feeds the follow-up PRs.

### B1 — balance controller sign (from Phase B)

- Pitch sign needs flip: `[ yes / no ]`
- Roll sign needs flip: `[ yes / no ]`
- Notes: `[                                                                  ]`

### B7 — drivetrain L/R / yaw convention (from Phase C)

- `0.3 0 0` produced: **BACKWARD** (2026-05-19) — pre-fix
- `0 0.3 0` produced: **LEFT** — correct
- `0 0 30` produced:  **CCW** — correct
- Disagreements vs REP-103: **vx inverted at the kinematics level** (vy and ω correct)
- Suspected wiring/sign issue: **kinematics formula vx coefficient sign**. Fixed in `src/drivetrain/OmniKinematics.h` (changed `-_sin[i] * v.vx` → `+_sin[i] * v.vx`). Bench re-verification pending.
- Note: this is the upstream fix for B7. B1 (controller pitch/roll sign) is now well-defined against the corrected kinematics — re-run Phase B after re-flash to decide whether `pitchKp`/`rollKp` sign flips are also required.

### General bench notes

```
[                                                                          ]
[                                                                          ]
[                                                                          ]
```

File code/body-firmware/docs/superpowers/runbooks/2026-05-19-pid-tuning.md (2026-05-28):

# PID Tuning — 2026-05-19

Bench-operator reference for tuning the balance controller's pitch/roll PIDs on the BB-8 sphere. Seven phases. Phases 1–2 are background you read once; phases 3–6 are the procedure you run at the bench; phase 7 is the wire-protocol reference card.

Each procedural step shows **Expected** behavior and an **Observed** blank for the operator to fill in. Conceptual sections are plain prose.

Cross-reference: do the bringup runbook (`2026-05-19-balance-bench-bringup.md`) first. This document assumes Phases A–E of bringup have already passed (OTA, sign-direction, kinematics convention, re-arm windup, fault envelope) — tuning gains on top of an unresolved sign error is unproductive.

---

## 1. Context

The balance controller's job is to keep the sphere upright by leaning into commanded velocity. There are two independent balance loops:

- **Pitch loop** (fore-aft tilt) → drives the body-frame `vx` output.
- **Roll loop** (left-right tilt) → drives the body-frame `vy` output.

Yaw (`omega`) is **cascaded** as of Commit 3+4: an inner gyro-Z rate PID closes the loop on yaw rate, and an outer heading-hold P loop captures the integrated heading when the stick is in the deadband and feeds a (clamped, LP-filtered) rate setpoint to the inner loop. Yaw can be reverted to pre-Commit-3 passthrough by zeroing both `yawRateKp` and `yawRateKi`. Phase F of the bringup runbook brings up both loops.

### Sphere sign convention (not Segway)

On a Segway, the wheels drive **toward** the lean to push the platform back upright. On the BB-8 sphere the geometry is inverted: the body sits inside the shell, and a forward lean of the body requires the wheels to push the **shell** in the opposite direction so the body's center of mass swings back over the contact patch. The recent fix in `src/drivetrain/OmniKinematics.h` (vx coefficient `-sin` → `+sin`) is what makes the `+vx` body-frame command produce a forward roll of the shell. The Phase B sign check in the bringup runbook locks this down.

### Safety envelope and arming

- The controller has a **Schmitt-triggered fault gate**. If the tilt magnitude (in `sin` space) exceeds `envelopeEnterSin` (default `sin 60° ≈ 0.866`), the controller latches a fault, resets both balance PIDs, and commands zero velocity until tilt comes back below `envelopeExitSin` (default `sin 55° ≈ 0.819`). The 5° gap is hysteresis — without it the gate would chatter at the threshold.
- `arm` / `disarm` / `kill` / `clearkill` / `armstate` verbs control the arming FSM. PIDs are reset on both arming edges (Disarmed→Armed and Armed→Disarmed) so accumulated I/D state cannot kick the wheels on re-engage.
- OTA upload force-disarms before flashing.
- The producer-silence auto-disarm killswitch has been **removed**. Armed state persists until an explicit verb, OTA, or fault trip. Short-term silence (<200 ms) still ramps `cmd` to zero via `STALENESS_TIMEOUT_MS` but does not disarm.
- The `kill` verb hard-brakes and latches Killed; only `clearkill` releases.

### Where to run this

**Robot must be ON THE GROUND or in a wheel-loaded cradle.** Free-spinning wheels hide both the windup jolt and the balance D-term effects — a robot that "looks fine on the bench stand" can be wildly mis-tuned on the ground. The fault envelope (60°/55°) is your friend during tuning: a robot that's about to tip will gate itself off rather than fall.

---

## 2. Parameter glossary

The full set is defined in `src/drivetrain/BalanceConfig.h`. Compiled defaults live in `RobotConstants::balanceConfig()` (`src/drivetrain/RobotConstants.h`). Live values are settable over WebSerial via `balance set <key> <value>` and persisted to NVS with `balance save`.

For each parameter: units, what it physically does, current default, and the observable symptoms of "too low" / "too high".

### `tiltPerVelocity` — command-to-lean gain

- **Units:** rad per (m/s).
- **Default:** `0.30` (1 m/s commanded → ~17° lean setpoint).
- **What it does:** Maps the operator's velocity command (`cmd.vx`, `cmd.vy`) into a target lean angle. The balance loop then drives wheels to achieve that lean. This is the *forward path*: high `tiltPerVelocity` means "aggressively lean for fast travel"; low means "stay near upright even when commanded fast".
- **Too low:** Robot won't move much even at full stick — the controller barely leans, so it barely accelerates.
- **Too high:** Robot tips trying to achieve the requested speed — the commanded lean exceeds the controller's catch authority. Caps at `maxTiltSetpoint` (next param) before that happens.

### `maxTiltSetpoint` — hard cap on commanded lean

- **Units:** rad.
- **Default:** `0.35` (~20°).
- **What it does:** Clips the output of `tiltPerVelocity * cmd.v` so the *requested* lean never exceeds this value, regardless of stick input. Keeps the commanded lean comfortably below the 60° fault envelope.
- **Tuner invariant:** `BalanceTuner::_set` rejects values `>= asin(envelopeEnterSin)`. You cannot set this to a value that would itself trip the fault gate.
- **Too low:** Maximum forward speed is throttled — you can't ask for an aggressive lean even if the robot could handle it.
- **Too high:** A burst of stick input requests a near-tipover lean; the controller is asked to balance at a setpoint that leaves no recovery margin.

### `pitchKp` — proportional restoring force (fore-aft)

- **Units:** m/s output per rad of pitch error.
- **Default:** `1.50`.
- **What it does:** This is the "spring". When the robot is leaning forward by `+X` rad (pitch_actual > pitch_target), the error is negative, so the PID emits `Kp * error` m/s of `vx` — wheels roll **backward**, which pushes the shell back so the body falls back toward upright. Stiffer Kp = stronger restoring force per unit of error.
- **Too low:** Robot tips and falls — the wheels barely move when tilted, no restoring force.
- **Too high:** Robot oscillates fore-aft. The wheels overshoot every correction; you see a clear ringing at the system's natural frequency (typically 1–5 Hz on a sphere this size).

### `pitchKi` — integrated pitch error

- **Units:** m/s output per (rad·s) of accumulated pitch error.
- **Default:** `0.0`.
- **What it does:** Sums error over time and pushes the output to eliminate any persistent offset. For a balance robot with a direct tilt measurement from the IMU, Kp alone usually gets you to zero steady-state — there's no sensor drift to integrate away. Useful only if there's a real physical bias (e.g. weight unevenly placed, wheel friction asymmetry) that Kp's proportional law can't fully cancel.
- **Anti-windup:** `PID::compute` clamps the integral to `[outputMin / Ki, outputMax / Ki]` so it cannot saturate the output indefinitely. The clamp prevents *runaway*, not lag — a wound-up integral will still take time to bleed off once the disturbance is gone.
- **Too low (e.g. 0):** Robot lists persistently in one direction at a small angle (1–3°). Kp wants to push but the proportional output equals the disturbance and equilibrium settles offset from upright.
- **Too high:** Slow-period oscillation (longer than Kp ringing), or a "leans further and further in one direction" before the anti-windup clamp kicks in and the controller eventually re-centers. Often trips the fault envelope.

### `pitchKd` — pitch rate damping

- **Units:** m/s output per (rad/s) of pitch rate.
- **Default:** `0.15`.
- **What it does:** Resists *angular velocity*. The PID computes `Kd * (-rate)` so a positive pitch rate (falling forward) produces a negative `vx` term, pushing back.
- **Critical implementation detail:** Read `BalancingDrivetrainController.cpp` lines 76–80. The D-term is fed the **raw gyro reading** (`cfg.gyroPitchSign * imuData.gyro.y`), **not** the numerical derivative of the pitch measurement. This matters because:
    - Gyro rate is a direct, low-noise hardware measurement. Numerical d/dt of pitch would amplify IMU quantization noise.
    - There's no `Kd * d(error)/dt` term that fights the setpoint when it changes — only the measurement's velocity is damped. Setpoint changes are smooth ramps, not derivative kicks.
    - **Kd here behaves like a tachometer brake.** "How fast am I rotating?" → directly proportional opposing wheel command. Tune it that way.
- **Too low:** Robot oscillates after each Kp correction — the spring rings without enough viscous damping.
- **Too high:** Wheels chatter / whine at IMU noise frequency (you can hear it as a high-pitched buzz from the motors). The D-term is amplifying gyro hash directly into wheel command.
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

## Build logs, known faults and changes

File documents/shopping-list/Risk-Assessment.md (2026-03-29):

# Risk Assessment

## WiFi and/or Bluetooth communication with the ESP32

The robot relies on wireless communication (WiFi and/or Bluetooth) with an external device (controller). The ESP32 supports both protocols, but can always cause unpredictable latency if not treated correctly and range may also become an issue in environments with interference. Since the robot's movement and camera feed both depend on this link, any communication failure directly impacts the core functionality of the project.

### Solutions
We will start by building a dedicated communication prototype in the first weeks we recieve the compenents: two ESP32s exchanging movement commands in a loop, where we measure latency and packet loss under realistic conditions. We will pick one primary protocol (most likely WiFi UDP for its low latency) and avoid running both WiFi and Bluetooth simultaneously unless strictly necessary.

## Different voltage requirements across components

The system includes components with very different power needs: DC motors typically run at 6–12V, while the ESP32 operates at 3.3V logic (5V input), and the camera module has its own requirements. Managing multiple voltage rails with converters introduces risks of noise on logic lines, brown-outs during motor startup, and incorrect wiring that could damage components. 

### Solutions
Before wiring anything, we will draw a complete power distribution schematic listing every component, its required voltage, and its peak current draw. We will then build a power prototype early on (wiring all consumers (ESP32, motors, camera) on the real batteries with the planned voltage converters) and verify that the ESP32 does not reset when the motors start. We will add decoupling capacitors on every power line.

## Magnetic coupling to hold the head

The head of the BB-8 is held onto the body using magnets. The coupling must be strong enough to keep the head attached during acceleration and direction changes, yet free enough to allow smooth rotation in any direction. Finding the right magnet strength, size, and placement is a physical problem that is difficult to reason about purely on paper. Additionally, strong magnets placed near the accelerometer or compass could interfere with sensor readings, introducing errors in the stabilization system.

### Solutions
We made several calculations on the head weight and the required magnets strenght that should guarentee good results.

## Sphere stability and wobble

The internal 3-wheeled chassis pushes the sphere from the inside using friction. If the weight distribution is uneven or the wheels are poorly positioned, the sphere will wobble, spin in place, or veer unpredictably. More critically, sudden acceleration or braking causes the internal chassis to shift momentum abruptly, which can throw the entire system off balance and send the sphere in an unintended direction. Controlling smooth, stable motion therefore requires both a well-balanced mechanical design and a reliable closed-loop control system using the accelerometer — and a failure in either layer will make the robot unusable.

### Solutions
To address sphere stability, we will place the heaviest components as low as possible on the chassis to keep the center of mass close to the ground, which passively reduces wobble. We will then use an accelerometer combined with a software control loop to continuously monitor and adjust the motor commands, compensating for unwanted movements in real time.

## Camera performance and feature support

The camera mounted in the head needs to deliver sufficient image quality to support features like face detection. An ESP32-CAM module can handle basic streaming at low frame rates, but real-time face detection using deep learning models requires significantly more processing power. If the camera is connected to the same ESP32 handling motor control, it may saturate the CPU and degrade both systems. The risk is not just whether the camera works, but whether it can run the intended features at an acceptable speed within the constraints of embedded hardware.

### Solutions
We will prototype the camera system completely independently, getting face detection running on a standalone device before any robot integration. We will use a dedicated processor for vision (a separate ESP32) so it never competes with motor control for CPU time. If on-board inference is too slow for real-time detection, we will offload the computation to an external laptop over WiFi: the robot streams video out, the laptop runs the detection model and sends back high-level commands. 

## Keeping the sphere small enough

All internal components(the chassis, motors, batteries, ESP32, wiring, and camera) must fit inside the sphere. The available volume is more constrained than it appears in early sketches. Cables, connectors, and the need for physical access (e.g., to recharge batteries or debug hardware) add hidden bulk. If the sphere is too small, the chassis cannot be built as designed; if it is made larger to compensate, the robot loses its aesthetic and may become harder to control mechanically.

### Solutions
This has already been done on the cad. We have left some margin for mistake.

## Insufficient motor torque

The motors must move the entire robot (chassis, batteries, and all electronics) by pushing against the inside of the sphere. If the motors lack sufficient torque, the robot will struggle to accelerate, climb slight inclines, or recover from perturbations. This risk is compounded by the indirect drive mechanism (friction against the sphere wall), which is inherently less efficient than direct drive. Motor selection must account for the total system weight, the friction coefficient between wheels and sphere, and the expected loads during normal operation.

### Solutions

We already estimated the required torque before ordering motors: calculating the total system weight and the expected friction force between wheels and sphere, and selecting motors that exceed this with clear margin. We will then build the chassis at its intended full weight and verify on a flat surface that the motors can accelerate and stop without stalling. If this isn't enough, we will add/create some kind of gear to adjust the power.

## Omni-wheel positioning causing excess friction or mechanical resistance

The three omni-wheels must be positioned at angles that allow movement in any direction while maintaining consistent contact with the inside of the sphere. If the geometry is wrong (wrong angles, wrong contact pressure, or misaligned axles) the wheels will generate lateral friction forces that resist motion rather than enabling it. This is a subtle mechanical design problem: small errors in wheel placement can create binding, uneven wear, or loss of directional control. It is also difficult to diagnose once the chassis is assembled inside the sphere.

### Solutions
We calulated the angles with the CAD and will print our own omni-wheels so we will be able to adjust them tout our specific requirements.

## Sphere structural integrity and cracking

The sphere is a critical structural component that must withstand continuous mechanical stress from internal forces, impacts with the environment, and repeated opening/closing if the system is accessible. Depending on the material (e.g., PLA, PETG, polycarbonate), the sphere may be prone to cracking, especially along layer lines if 3D printed. Small defects or stress concentrations (such as holes for ventilation or assembly seams) can propagate into larger fractures over time. A cracked sphere not only compromises the aesthetic but can completely break the locomotion system, as the internal traction relies on a smooth and rigid surface.

### Solutions
We made sevral tests with smaller 3-D printed spheres and talked with Sebastien who told us the integrety shouldn't be a problem.

## Imperfect sphere geometry

If the sphere is not perfectly round (due to manufacturing tolerances, deformation, poor assembly, or uneven material thickness), the robot may experience irregular motion. Even small deviations in curvature can change how the omni-wheels contact the surface, creating vibration, wobble, or inconsistent rolling behavior. Since the entire locomotion concept depends on predictable contact between the wheels and the sphere, geometric imperfections can significantly degrade performance.

### Solutions
We will validate the sphere's roundness before assembling the chassis inside it: rolling it on a flat surface and checking for wobble, and measuring the internal diameter at multiple points. Once 3-D printed, we will sand and finish the internal surface to reduce irregularities.

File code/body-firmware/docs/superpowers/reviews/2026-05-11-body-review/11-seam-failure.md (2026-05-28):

# Cell 11 — Seam: Failure / Disconnect / Failsafe Paths

Scope: every path that can cost comms or sensors; whether each ends at *motors-off within a bounded time*; whether recovery is clean.

Anchored at f8ca95f. Files of record: `src/main_robot.cpp`, `src/input/WebSocketCommandProducer.{h,cpp}`, `src/motor/driver/L298NDriver.{h,cpp}`, `src/drivetrain/OmniDrivetrain.h`, `src/control/PID.h`, `src/imu/BNO055IMU.h`, `src/util/Lifecycle.h`, `test/`.

---

## Trigger → motors-off table

| # | Trigger | Path to "motors-off" | Upper bound | Enforced by | Active brake? |
|---|---|---|---|---|---|
| T1 | WiFi drops mid-run | Latch keeps last cmd; producer task still up; no fresh frames → staleness ramp → cmd=0 | **200 ms** (ramp end) | `main_robot.cpp:174-183` (ramp) | No — PIDs hold 0 RPM, L298N writes 0/0 (coast) |
| T2 | WS client clean disconnect (FIN) | `WStype_DISCONNECTED` clears `_connected`; cmds stop → ramp → cmd=0 | **200 ms** | same ramp | No |
| T3 | WS half-open TCP (no FIN, no commands) | Heartbeat 2 s/1 s/2 retries = ~6 s to detect; but ramp triggers at **200 ms** because no new frames hit latch | **200 ms** to motors-coast, **~6 s** to `_connected=false` | ramp (motors), heartbeat (flag only) | No |
| T4 | WS half-open with stale-cmd spam (e.g. client TCP buffered, OS resends old frames) | If frames keep arriving, latch keeps refreshing; ramp NEVER fires → motors hold last cmd indefinitely | **UNBOUNDED** until heartbeat (~6 s) — *and even then nothing in code consumes the flag* | nothing | No — see C11-P0-01 |
| T5 | Operator sends no commands >200 ms | `last_fresh_ms` ages past `STALENESS_TIMEOUT_MS` → ramp → cmd=0 | **200 ms** | ramp | No |
| T6 | BNO055 I²C error mid-run | `g_imu.read()` returns whatever Adafruit_BNO055 returns on bus failure; **no error check**; control loop continues with stale/garbage IMU. PIDs still drive motors. | **NEVER** — never trips staleness, TWDT, or any other failsafe | nothing | No — see C11-P0-02 |
| T7 | Motor driver fault (encoder stops reporting) | `getFilteredRPM()` returns 0; PID sees error = setpoint − 0 = setpoint; integrator winds up to saturation. PWM goes to max on that wheel. | **NEVER** — runaway on the un-faulted side | nothing | No — see C11-P0-03 |
| T8 | OTA flash starts | `ArduinoOTA.onStart` → `g_producer->stop()` (blocks ≤1 s). No new frames → ramp → cmd=0, *then* flash writes begin | **200 ms** (after `stop()` returns) | ramp | No — motors coast through flash; see C11-P0-04 |
| T9 | Power glitch / brownout | ESP32 brownout detector is at chip default (~2.43 V), no software policy. On reset, all GPIOs revert to high-Z. L298N inputs floating → driver output undefined. After boot, motors are coast until `g_motor*.begin()` (pin OUTPUT, default LOW). | reset → re-arm in **~hundreds of ms to multiple seconds** depending on WiFi-blocking `connectWifi()` (30 s timeout) | none specific; ESP32 brownout det. is enabled by default but no software callback | No |
| T10 | TWDT fires (1 s, panic=true) | `esp_task_wdt_init(1 s, true)` → panic → reset. Motors then coast (T9 path). | **1 s** to reset; full reboot cycle (WiFi reconnect 30 s budget) before re-armable | TWDT | No — coast during reset window |

> All "motors-coast" rows: at zero command the PIDs still run with setpoint=0. With deadband=5 RPM and measurement < 5 RPM, `PID::compute` calls `reset()` and returns `0.0f` (`PID.h:22-24`). L298N at 0.0 writes `analogWrite(fwd,0); analogWrite(rev,0)` (`L298NDriver.cpp:24-28`) — **coast, not brake**. On an incline the robot rolls.

```json
{
  "cell": 11,
  "scope": "seam-failure-failsafe-paths",
  "anchor_commit": "f8ca95f",
  "findings": [

    {
      "id": "C11-P0-01",
      "title": "Stale-but-arriving frames bypass the staleness ramp entirely",
      "severity": "P0",
      "lens": "safety",
      "file": "src/main_robot.cpp",
      "lines": "160-183",
      "quote": "auto fresh = g_latch->read();\n        const uint32_t now = millis();\n        if (fresh.has_value()) {\n            last_known      = *fresh;\n            last_fresh_ms   = now;\n            have_seen_fresh = true;\n        }\n\n        // 2) Drive command via staleness alone. The producer's connected()\n        //    flag can lie on half-open TCP; age < 200ms is the actual safety\n        //    net so we don't gate on connected() anymore.",
      "claim": "The staleness clock is reset by ANY frame in the latch, not by an operator-side timestamp. If a stuck client / proxy / OS retransmit replays a non-zero command, the ramp never fires; motors hold that command indefinitely. The comment above the code claims age<200 ms is 'the actual safety net' but the clock measures 'time since something landed in the latch', not 'time since operator intent'. There is no monotonic-counter or operator timestamp in `CommandFrameParser` to detect replays. Combined with T4, a wedged operator-side TCP stack can drive at full speed for >>6 s with zero new operator intent.",
      "impact": "Unbounded time-to-motors-off in the half-open-with-stale-frames scenario. This is the *entire* point of the staleness contract and it is bypassed.",
      "remediation": "Add a wire-protocol field `seq` (u32 monotonic) or `ts_ms` and reset `last_fresh_ms` only when the seq advances. Optionally, gate also on `_connected.load()` once the heartbeat-driven flag is honored; today line 170-171 explicitly chooses not to.",
      "verification": "Add a native test that pushes the SAME `BodyVelocity{1,0,0}` into the latch at 100 Hz for >200 ms and asserts the drive command decays — it currently won't."
    },

    {
      "id": "C11-P0-02",
      "title": "IMU read failure is silent — control loop keeps driving on stale/garbage data",
      "severity": "P0",
      "lens": "safety",
      "file": "src/imu/BNO055IMU.h",
      "lines": "33-80",
      "quote": "IMUReading read() override {\n        BB8_ASSERT(_initialized, \"BNO055: read() called before begin()\");\n        if (!_initialized) return IMUReading{};\n\n        IMUReading r;\n\n        if (_fields & IMUField::Quaternion) {\n            auto q = _bno.getQuat();",
      "claim": "`BNO055IMU::read()` never returns an error and never reports I2C failure. `Adafruit_BNO055::getQuat()` on bus error returns a zero quaternion; downstream `IMUReading` carries identity/zero defaults indistinguishable from valid silence. `main_robot.cpp:186-187` consumes the reading and passes it to `PassthroughDrivetrainController::update` without checking; for the current passthrough this is benign, but the moment any stabilizer controller is wired (see `docs/controller-discussion.md`), an undetected IMU failure will drive open-loop and likely runaway. Even today, the control task can block for a long time inside `_bno.getQuat()` if I2C stretches — see TWDT bound (1 s), so worst case is reset, not runaway. Still, no error signal to the rest of the system.",
      "impact": "Future stabilizer controllers will fail silently with garbage IMU. Today: undetected sensor degradation; T6 row in the trigger table = NEVER.",
      "remediation": "Return `std::optional<IMUReading>` or a `bool ok` from `IMU<T>::read()`. Adafruit_BNO055 exposes `getEvent()` returning bool and `verify()`; wrap with a consecutive-failure counter, and either zero the command or call `controller->stop()` after N misses.",
      "verification": "Add a stub `Adafruit_BNO055` mock that fails I2C and assert the control loop reacts."
    },

    {
      "id": "C11-P0-03",
      "title": "Encoder/motor fault causes PID windup and one-wheel runaway",
      "severity": "P0",
      "lens": "safety",
      "file": "src/drivetrain/OmniDrivetrain.h",
      "lines": "25-33",
      "quote": "void update(float dt) override {\n        for (auto* m : _motors) m->update();\n\n        float s0 = _pids[0]->compute(_targetRPMs[0], _motors[0]->getFilteredRPM(), dt);\n        float s1 = _pids[1]->compute(_targetRPMs[1], _motors[1]->getFilteredRPM(), dt);\n        float s2 = _pids[2]->compute(_targetRPMs[2], _motors[2]->getFilteredRPM(), dt);",
      "claim": "If an encoder disconnects or a motor stalls under load while the operator commands nonzero, `getFilteredRPM()` reports ~0 while `_targetRPMs[i]` stays at the command. Error = setpoint − 0 = full setpoint; PID integrator winds up to its anti-windup clamp (output/Ki), output saturates at +1.0; that wheel goes to full PWM. The other two wheels keep tracking — the result is a violent yaw or spin. There is no per-wheel fault detection (no |error| threshold + timer, no current sense, no encoder-timeout check in `FIT0186Motor::update`).",
      "impact": "Single-point sensor failure → runaway on the un-faulted axis. The omni-tilt geometry means even one bad wheel can launch the sphere.",
      "remediation": "Add a per-motor fault detector in `FIT0186Motor`: if commanded |PWM| > threshold for >N ms and |measured RPM| ~= 0, raise a fault flag. `OmniDrivetrain::update` then either calls `stop()` on the offending motor (passing fault upward) or reduces all commanded outputs to zero via `controller->stop()`.",
      "verification": "Native test: drive `OmniDrivetrain` with a `MockMotor` that ignores `setSpeed` (forces RPM=0) and assert fault flag fires within bound."
    },

    {
      "id": "C11-P0-04",
      "title": "OTA path does not actively brake motors; only stops the producer",
      "severity": "P0",
      "lens": "safety",
      "file": "src/main_robot.cpp",
      "lines": "104-110",
      "quote": "ArduinoOTA.onStart([]() {\n        // Stop accepting new commands. Once the producer is gone, the staleness\n        // ramp in controlTask will drive motors to zero within 200 ms before\n        // the firmware actually overwrites flash.\n        Serial.println(\"[ota] update starting; halting teleop\");\n        if (g_producer) g_producer->stop();\n    });",
      "claim": "(a) The onStart callback only stops the producer; it does NOT call `g_controller->stop()` or `g_drivetrain.stop()` or zero `_targetRPMs`. The control loop continues running through the ramp and reaches PWM=0 (coast) but the wheels are not actively braked. (b) `g_producer->stop()` blocks up to 1 s on `_exitSemaphore` (`WebSocketCommandProducer.cpp:74`) — that 1 s is added to the 200 ms ramp, so total deadline before flash overwrite = ~1.2 s, comfortably inside ArduinoOTA's own handshake window, but not documented. (c) There is no `onProgress` callback registered; the control task keeps running during flash and competes for flash/CPU with the OTA writer. (d) After `onEnd` the device reboots; on reboot `connectWifi()` blocks for up to 30 s before the control task even starts — during this window motors are coast (T9). (e) If `onError` fires, the producer has been destroyed (`stop()` calls `delete _server; _server = nullptr;`) and there is no `start()` to bring it back — operator must power-cycle.",
      "impact": "OTA-mid-flight coasts the sphere from whatever motion it was in; could roll off a table during the 200 ms + flash window. OTA failure leaves the device in a half-armed state (control loop alive, no producer) until manual reset.",
      "remediation": "In `onStart` also call `g_controller->stop()` (which calls `OmniDrivetrain::stop()` → `motor->brake()` on all three → L298N HIGH/HIGH = active short). In `onError` re-arm: `g_producer->start()` again. Optionally suspend the control task entirely during flash with `vTaskSuspend` and resume in `onEnd/onError`.",
      "verification": "Manual flash test: command a forward velocity, trigger OTA, observe whether wheels coast or brake (audible click on H-bridge brake)."
    },

    {
      "id": "C11-P0-05",
      "title": "OmniDrivetrain::stop() is dead code — no runtime trigger reaches active-brake",
      "severity": "P0",
      "lens": "safety",
      "file": "src/main_robot.cpp",
      "lines": "144-206",
      "quote": "void controlTask(void* /*arg*/) {\n    // Subscribe to the Task Watchdog. If this loop hangs (e.g. I2C bus\n    // stretch on the IMU), TWDT panics and resets — preferable to motors\n    // stuck at last PWM with no operator recovery.\n    esp_task_wdt_add(NULL);",
      "claim": "Grep across `src/` confirms `OmniDrivetrain::stop()` is invoked only by `PassthroughDrivetrainController::stop()` and the off-runtime `main_drivetrain_test.cpp`. `PassthroughDrivetrainController::stop()` has zero callers in `main_robot.cpp` (T1-T8 all end in PWM=0 coast, not `motor->brake()`). Net effect: `Motor::brake()` and the L298N HIGH/HIGH active-brake path are unreachable in production. The 'emergency stop' API exists but is never triggered.",
      "impact": "Across all 9 failure rows, motors-off means coast, never brake. On an inclined surface the robot will roll. The codebase has a functional brake but no wiring to invoke it.",
      "remediation": "Wire `g_controller->stop()` into: (1) OTA onStart (after producer.stop()), (2) post-ramp once `age >= STALENESS_TIMEOUT_MS` AND `have_seen_fresh` (latch the brake instead of coast), (3) a TWDT pretrigger handler via `esp_task_wdt_init_panic` / `esp_register_shutdown_handler`. Even if (3) only has milliseconds before reset, calling `motor->brake()` writes the H-bridge inputs before chip reset — better than coast.",
      "verification": "Native test: assert `mock_motor.brake_count > 0` after a simulated 200 ms staleness episode — currently 0."
    },

    {
      "id": "C11-P1-06",
      "title": "Boot races: WS server accepts commands before TWDT/control task arm",
      "severity": "P1",
      "lens": "safety",
      "file": "src/main_robot.cpp",
      "lines": "228-247",
      "quote": "g_latch      = new CommandLatch<BodyVelocity>();\n    g_producer   = new WebSocketCommandProducer(*g_latch, WS_PORT);\n    g_controller = new PassthroughDrivetrainController(g_drivetrain, g_imu);\n\n    g_producer->start();\n\n    initOta();\n\n    // Tighten the global Task Watchdog timeout. Affects IDLE tasks too, but\n    // 1s is comfortably above their normal slack.\n    esp_task_wdt_init(TWDT_TIMEOUT_S, true);\n\n    xTaskCreatePinnedToCore(\n        &controlTask,",
      "claim": "Order: producer starts → OTA inits → TWDT inits → control task is created last. Between `g_producer->start()` (line 232) and `xTaskCreatePinnedToCore(controlTask, ...)` (line 240) the WS server is live and writing to the latch but nothing reads it. If a client connects in this ~ms-scale window the first command is delivered, then the control task starts and the latch read returns a `last_known` from before-boot intent. Worse: control task subscribes to TWDT *after* `esp_task_wdt_init(1 s, panic=true)` — IDLE0/IDLE1 are TWDT-subscribed in Arduino-ESP32 by default; ws_prod ran briefly under panic=true watchdog already.",
      "impact": "Tiny but non-zero arming-window where the first operator command can leak into post-boot state. Boot is also slow (30 s WiFi timeout) so an impatient operator may already be banging on the WS.",
      "remediation": "Reorder: create control task first (with an initial 'safety-disarmed' flag that forces drive_cmd=0 regardless of latch). Only flip the flag once `setup()` completes. Or: do not call `g_producer->start()` until after the control task is alive."
    },

    {
      "id": "C11-P1-07",
      "title": "Half-open detection takes ~6 s but `_connected` is unused on hot path",
      "severity": "P1",
      "lens": "safety",
      "file": "src/input/WebSocketCommandProducer.cpp",
      "lines": "47-52",
      "quote": "_server->onEvent([this](uint8_t num, WStype_t type, uint8_t* payload, size_t length) {\n        this->onWsEvent(num, static_cast<uint8_t>(type), payload, length);\n    });\n    // Detect half-open TCP within ~6s: ping every 2s, fail after 1s + 2 retries.\n    _server->enableHeartbeat(2000, 1000, 2);",
      "claim": "Heartbeat config matches the comment (ping 2 s, pong-timeout 1 s, 2 retries → upper bound 2 s × 3 = 6 s before disconnect event). The control loop intentionally ignores `_connected` (`main_robot.cpp:170-171`). In the half-open-silent case (T3) ramp catches it at 200 ms — fine. In half-open-with-stale-frames (T4, see C11-P0-01) ramp doesn't catch it and `_connected` is ignored, so detection is effectively never. Even when heartbeat does fire the disconnect event, the producer task and control loop don't observe it as anything other than the absence of new frames — which the ramp already handles when frames stop.",
      "impact": "The 6 s heartbeat is currently observability-only. Pair with C11-P0-01 — the *combination* is the runaway.",
      "remediation": "Either (a) on `WStype_DISCONNECTED` for the active client, write a zero `BodyVelocity` into the latch immediately AND mark a 'disconnect-latched' flag the control loop reads to call `controller->stop()`; or (b) gate the staleness clock on operator-side sequence numbers (C11-P0-01) so half-open with replay is detected at 200 ms regardless."
    },

    {
      "id": "C11-P1-08",
      "title": "PID integrator persists across disconnect/reconnect cycles",
      "severity": "P1",
      "lens": "safety",
      "file": "src/main_robot.cpp",
      "lines": "144-206",
      "quote": "BodyVelocity last_known{};\n    uint32_t     last_fresh_ms = 0;\n    bool         have_seen_fresh = false;",
      "claim": "On WS disconnect → reconnect, the control task's locals reset only on a process reset, not on a producer-restart. `_targetRPMs[]` inside `OmniDrivetrain` and the three `PID` integrators are also never reset by any code path the runtime exercises (`PID::reset()` is only called from `OmniDrivetrain::stop()` which is dead code — see C11-P0-05). After a stale-disarm-then-reconnect, the new operator inherits whatever integrator state the previous session left behind, including possibly saturated integrators if the previous session ended under load.",
      "impact": "Reconnect surprise — first command after reconnect can produce a kick. The PID deadband zero-snap path (`PID.h:22-24`) resets only when *both* setpoint and measurement are near zero, so a snapshot at fast-decel may not snap.",
      "remediation": "On `WStype_DISCONNECTED` for the active client OR on staleness timeout, the control loop should call `g_controller->stop()` once (latched) — this resets PIDs and `_targetRPMs`. Re-arm on first fresh frame after reconnect."
    },

    {
      "id": "C11-P1-09",
      "title": "No brownout policy; no brake-on-power-loss",
      "severity": "P1",
      "lens": "safety",
      "file": "src/main_robot.cpp",
      "lines": "210-250",
      "quote": "void setup() {\n    Serial.begin(115200);\n    delay(200);\n    Serial.println(\"BB-8 main_robot starting.\");\n\n    Wire.begin(I2C_SDA, I2C_SCL);\n\n    g_motor0.begin();\n    g_motor1.begin();\n    g_motor2.begin();",
      "claim": "Grep across the body-firmware tree: zero references to `brownout`, `setBrownoutDetector`, `WRITE_PERI_REG(RTC_CNTL_BROWN_OUT_REG...)`, or `esp_brownout_register`. ESP32-Arduino enables the brownout detector by default (~2.43 V) and brownout → reset is the chip-level behavior. The reset path is T9: GPIOs go high-Z (good — L298N inputs floating → 0 V → both LOW → coast), motors coast through the reset, then `g_motor*.begin()` sets pins OUTPUT/LOW (still coast), then WiFi blocks for up to 30 s. With L298N, this is acceptable (coast, not free-PWM). With BTS7960 in the future, the boot-time pin behavior must be re-validated — BTS7960 has explicit enable lines.",
      "impact": "On battery sag during high-current acceleration, the chip resets, motors coast for the duration of the reset+reconnect cycle (could be tens of seconds). On an incline this rolls. No active-brake-on-brownout path.",
      "remediation": "Add an `esp_register_shutdown_handler` that calls `g_drivetrain.stop()` to brake before reset. Add a brownout pretrigger via `esp_brownout_register_callback` (ESP-IDF), and consider raising brownout threshold for early warning. Also: at boot, set `g_lastWifiConnectedMs = millis()` before the 30 s `connectWifi` loop to avoid the post-boot reboot watchdog tripping during a slow WiFi join."
    },

    {
      "id": "C11-P1-10",
      "title": "loopTask (Arduino main) is not TWDT-subscribed — OTA hang is invisible",
      "severity": "P1",
      "lens": "realtime",
      "file": "src/main_robot.cpp",
      "lines": "252-264",
      "quote": "void loop() {\n    // Housekeeping: OTA poll + WiFi reboot watchdog. Control runs in dedicated\n    // tasks. Tick at 10 Hz so OTA initiate requests are answered promptly.\n    ArduinoOTA.handle();\n\n    if (WiFi.status() == WL_CONNECTED) {\n        g_lastWifiConnectedMs = millis();\n    } else if (millis() - g_lastWifiConnectedMs > WIFI_OFFLINE_REBOOT_MS) {\n        Serial.println(\"FATAL: WiFi offline >30s — restarting.\");\n        ESP.restart();\n    }",
      "claim": "`controlTask` (line 148) and `taskBody` (`WebSocketCommandProducer.cpp:103`) both subscribe to TWDT. Arduino's `loopTask` is created by the framework and is NOT subscribed in this code. If `ArduinoOTA.handle()` deadlocks or `WiFi.status()` blocks, the housekeeping task hangs silently — the control task keeps running, motors keep tracking commands (or staleness ramp). The 30 s WiFi offline reboot watchdog is itself in the unwatched task, so a hang of loopTask defeats the WiFi watchdog.",
      "impact": "A class of OTA/WiFi-stack bugs becomes silent: no TWDT panic, no reset. The control task happily runs without WiFi-recovery oversight.",
      "remediation": "Either subscribe loopTask to TWDT (`esp_task_wdt_add(NULL); esp_task_wdt_reset()` inside `loop`) — but the function is short and a 1 s budget is generous — or move the WiFi-reboot watchdog into a dedicated TWDT-subscribed task."
    },

    {
      "id": "C11-P1-11",
      "title": "Zero test coverage of failure paths",
      "severity": "P1",
      "lens": "quality",
      "file": "test/",
      "lines": "all",
      "quote": "test_omni_drivetrain/test_omni_drivetrain.cpp:    dt.stop();",
      "claim": "Native test inventory under `test/`: pid, omni_kinematics, omni_drivetrain (stop is tested in isolation), passthrough_controller (stop tested in isolation), command_latch, command_frame_parser, fit0186_motor, l298n_driver, bts7960_driver, moving_average, bno055_imu, mock_command_producer. NONE of them simulate: a staleness ramp, a WS disconnect, an IMU read failure, an encoder fault, an OTA hook firing, a TWDT-pretrigger, or a brownout shutdown. The seam between WS producer + latch + control task + ramp + drivetrain is untested as an integrated unit. C11-P0-01 (replay), C11-P0-02 (IMU silent), C11-P0-03 (encoder fault) are all easy to express as native tests with the existing mocks (`test_mock_motor.h`, `MockCommandProducer`) and would have caught these issues.",
      "impact": "All safety claims in this review are static-analysis claims; nothing prevents regressions.",
      "remediation": "Add `test_staleness_ramp/` (drive `controlTask`-equivalent function with controlled clock + latch), `test_disconnect_recovery/`, `test_imu_failure/` (mock IMU returning identity quat), `test_encoder_fault/` (mock motor returning RPM=0 under nonzero command)."
    },

    {
      "id": "C11-P2-12",
      "title": "Zero-command coast vs hold-position on an incline",
      "severity": "P2",
      "lens": "safety",
      "file": "src/control/PID.h",
      "lines": "22-26",
      "quote": "if (_deadband > 0.0f && std::abs(setpoint) < 1e-6f && std::abs(measurement) < _deadband) {\n            reset();\n            return 0.0f;\n        }",
      "claim": "Definition of 'motors off' in this codebase = setpoint=0 to PID, which under the deadband snap (setpoint≈0 AND |measured|<5 RPM) returns 0.0 and resets the integrator. If the robot is on an incline and rolling, |measured| > 5 RPM → no snap; PID actively fights with `error = -measurement`, output = `Kp * (-measurement)` = `-0.005 * measured_rpm`. At 50 RPM that's −0.25 → 25% reverse PWM. So 'zero command' is NOT 'PWM=0' on a moving robot — the PID brakes electrically (good, behavior-wise) but it's not what the table above calls 'coast'. On the *flat* with momentum the PIDs do hold position roughly. On an incline the PIDs fight the gravity-induced wheel rotation but can be overpowered. This is subtler than the context doc states.",
      "impact": "The 'staleness → motors off' wording in the context oversimplifies. Behavior is 'PIDs actively try to hold zero RPM' for as long as they can — which is *better* than coast for safety, but not the same as brake. And once the deadband snap fires (when the bot is nearly stopped), motors release.",
      "remediation": "Document this behavior explicitly. Decide whether the desired end-state is 'hold zero RPM' (current) or 'active brake' (`motor->brake()` short via L298N HIGH/HIGH). On an incline the latter is more conservative."
    },

    {
      "id": "C11-P2-13",
      "title": "Producer rejected client path can leak repeated connect attempts (no rate limit)",
      "severity": "P2",
      "lens": "safety",
      "file": "src/input/WebSocketCommandProducer.cpp",
      "lines": "121-132",
      "quote": "case WStype_CONNECTED: {\n            // Single-client policy: accept the first client, reject the rest.\n            // Two operators sending commands would oscillate the latch.\n            uint8_t expected = kNoClient;\n            if (_activeClient.compare_exchange_strong(expected, clientNum)) {\n                _connected = true;\n                Serial.printf(\"[ws] client %u connected\\n\", clientNum);\n            } else {\n                Serial.printf(\"[ws] client %u rejected (active=%u)\\n\", clientNum, expected);\n                if (_server) _server->disconnect(clientNum);\n            }\n            break;\n        }",
      "claim": "A second connecting client is disconnected, but each rejection runs `Serial.printf` synchronously on the ws_prod task. An attacker (or buggy client) hammering connect attempts can hold the WS task in Serial-flushing for extended periods, starving the WS heartbeat poll and indirectly degrading T3 detection time. Also, `Serial.printf` of `parse_fail` is rate-limited (`logParseFail` line 184) but the connect-reject log is not.",
      "impact": "Low — needs malicious/buggy LAN client. Worth a 1 Hz rate-limit on connect-reject logging and possibly an IP-level cooldown via `server->disconnect`.",
      "remediation": "Rate-limit connect-reject logs identically to `logParseFail`. Optionally maintain a small recent-rejected-IP set."
    }
  ],
  "seam_questions_answered": {
    "Q1_bounded_time_to_motors_off": "See trigger table. Bounded for T1/T2/T3/T5/T8 (~200 ms ramp). UNBOUNDED for T4 (stale-frames replay — C11-P0-01), T6 (IMU failure — C11-P0-02), T7 (encoder fault — C11-P0-03). For T10 (TWDT) bounded at 1 s but reset path is also coast.",
    "Q2_zero_command_vs_pwm_zero": "Not the same. Zero command → PID with setpoint=0; deadband snap returns 0.0 only when |measured|<5 RPM. Above 5 RPM the PID actively brakes electrically (Kp*-measured). On incline rolling fast the PID is being asked to brake but is rate-limited by Kp=0.005. See C11-P2-12.",
    "Q3_omni_drivetrain_stop_unreachable": "Confirmed dead code in main_robot.cpp. Only invoked by main_drivetrain_test.cpp and the unwired PassthroughDrivetrainController::stop(). Should be called from: OTA onStart (after producer.stop), post-staleness-timeout (latch a brake state), and ideally a TWDT shutdown handler. See C11-P0-05.",
    "Q4_ota_mid_flight": "onStart calls producer.stop() only — no controller.stop(), no motor.brake(). No onProgress. onEnd reboots. onError leaves producer destroyed and unrecoverable without power cycle. See C11-P0-04.",
    "Q5_half_open_tcp": "Heartbeat 2s/1s/2 retries = ~6s detection. _connected flag is intentionally not consulted on hot path (main_robot.cpp:170-171). Staleness ramp covers half-open-silent case at 200 ms; does NOT cover half-open-with-replay-frames. See C11-P0-01 + C11-P1-07.",
    "Q6_reconnect_path": "Not clean. Locals in controlTask (last_known, last_fresh_ms, have_seen_fresh) only reset on process restart. _targetRPMs and PID integrators are never reset by any runtime path (only by dead OmniDrivetrain::stop). See C11-P1-08.",
    "Q7_twdt_panic": "1 s, panic=true. Subscribed: controlTask + ws_prod task. NOT subscribed: Arduino loopTask (C11-P1-10). On reset motors coast — no brake-on-power-loss handler. See C11-P1-09.",
    "Q8_brownout": "Zero references in code. ESP32-Arduino default detector at ~2.43V → reset. Coast-through-reset with L298N. No software policy. See C11-P1-09.",
    "Q9_boot_armed_state": "Producer starts BEFORE control task is created (lines 232 vs 240). Tiny race window where WS server is live but no consumer of the latch. WiFi join blocks up to 30 s and reboot watchdog timer (g_lastWifiConnectedMs initialized to 0) could trip immediately post-boot if WiFi join is slow. See C11-P1-06.",
    "Q10_test_coverage": "Zero failure-path tests. All findings P0/P1 above are easy to express in the existing native test harness. See C11-P1-11."
  }
}
```

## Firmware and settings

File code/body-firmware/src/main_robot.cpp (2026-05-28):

/*
 * BB-8 Body Firmware — MIT 2026 SP, Team Sphere
 * Alessandro Lombardini, with assistance from Claude (Anthropic)
 *
 * End-to-end teleop: WebSocket producer (Core 0) → CommandLatch →
 * 100Hz control task (Core 1) → BalancingDrivetrainController → OmniDrivetrain.
 * Dead-window policy: instant stop on producer disconnect, linear ramp during
 * 200ms staleness window, hard stop after.
 */

#include <Arduino.h>
#include <Wire.h>
#include <freertos/FreeRTOS.h>
#include <freertos/task.h>
#include <esp_task_wdt.h>

#include "BodyVelocity.h"
#include "OmniDrivetrain.h"
#include "BNO055IMU.h"
#include "L298NDriver.h"
#include "FIT0186Motor.h"
#include "PID.h"
#include "RobotConstants.h"
#include "pins.h"

#include "sync/CommandLatch.h"
#include "WebSocketCommandProducer.h"
#include "BalancingDrivetrainController.h"
#include "BalanceTuner.h"
#include "BalanceConfigStorage.h"
#include "ArmingState.h"
#include "BalanceHttpApi.h"
#include "ArmingHttpApi.h"
#include "BalanceTelemetry.h"
#include "BalanceTelemetryWs.h"
#include "BalanceTelemetryHttpApi.h"
#include "RemoteSerial.h"

#include "BringUp.h"
OTA_SAFE_MODE_FOR("bb8-robot");

namespace {

using RobotConstants::STALENESS_TIMEOUT_MS;
using RobotConstants::CONTROL_PERIOD_MS;

constexpr uint16_t WS_PORT                  = 80;
constexpr uint32_t TWDT_TIMEOUT_S           = 1;     // tighter than Arduino default ~5s
constexpr uint32_t LOOP_TICK_MS             = 100;   // 10 Hz housekeeping
constexpr uint32_t CAL_PRINT_PERIOD_MS      = 500;
constexpr uint32_t CAL_POLL_PERIOD_MS       = 50;

constexpr uint32_t CONTROL_TASK_STACK_BYTES = 8192;
constexpr UBaseType_t CONTROL_TASK_PRIORITY = 4;
constexpr BaseType_t  CONTROL_TASK_CORE     = 1;

constexpr int I2C_SDA = 21;
constexpr int I2C_SCL = 22;

DrivetrainConfig g_config = RobotConstants::drivetrainConfig();

L298NDriver g_driver0(MOTOR0_PINS);
L298NDriver g_driver1(MOTOR1_PINS);
L298NDriver g_driver2(MOTOR2_PINS);

FIT0186Motor<5> g_motor0(g_driver0, MOTOR0_ENCODER);
FIT0186Motor<5> g_motor1(g_driver1, MOTOR1_ENCODER);
FIT0186Motor<5> g_motor2(g_driver2, MOTOR2_ENCODER);

PID g_pid0(0.005f, 0.002f, 0.0005f, -1.0f, 1.0f, 5.0f);
PID g_pid1(0.005f, 0.002f, 0.0005f, -1.0f, 1.0f, 5.0f);
PID g_pid2(0.005f, 0.002f, 0.0005f, -1.0f, 1.0f, 5.0f);

OmniDrivetrain g_drivetrain(g_motor0, g_motor1, g_motor2, g_config, g_pid0, g_pid1, g_pid2);

BNO055IMU g_imu(0x28, &Wire,
                IMUField::Quaternion | IMUField::Euler |
                IMUField::Gyro | IMUField::Calibration);

// Constructed in setup() after Wire/IMU are up, so FreeRTOS objects
// (queue inside the latch, server/task inside the producer) are created
// in a known-good runtime context rather than during C++ static init.
CommandLatch<BodyVelocity>*      g_latch      = nullptr;
WebSocketCommandProducer*        g_producer   = nullptr;
BalancingDrivetrainController*   g_controller = nullptr;
BalanceTuner                     g_tuner;

const char* armingStateName(ArmingState::State s) {
    switch (s) {
        case ArmingState::State::Disarmed: return "Disarmed";
        case ArmingState::State::Armed:    return "Armed";
        case ArmingState::State::Killed:   return "Killed";
    }
    return "?";
}

// RemoteSerial verb dispatcher: arm / disarm / kill / clearkill / armstate.
// Whitespace-trimmed; unknown verbs echo back to the browser. Mirrors the
// WebSocket producer's control-frame routing for bench operation without UI.
//
// arm/disarm/kill produce no echo here — ArmingState::* logs the transition
// itself via arming_log() (Serial + RemoteSerial), so a second print would
// duplicate. armstate is a pure query and clearkill from non-Killed is a
// FSM no-op, so both still echo the current state explicitly.
void handleRemoteSerialLine(const String& line) {
    String verb = line;
    verb.trim();
    if (verb == "arm") {
        ArmingState::arm();
    } else if (verb == "disarm") {
        ArmingState::disarm();
    } else if (verb == "kill") {
        ArmingState::kill();
    } else if (verb == "clearkill") {
        ArmingState::clearKill();
        RemoteSerial::printf("[arming] %s\n", armingStateName(ArmingState::get()));
    } else if (verb == "armstate") {
        RemoteSerial::printf("[arming] %s\n", armingStateName(ArmingState::get()));
    } else {
        // Fall through to the balance tuner: it consumes lines that begin with
        // `balance ` and silently ignores anything else, so truly-unknown verbs
        // become no-ops here.
        g_tuner.handle(line);
    }
}

// Block until the BNO055 is calibrated enough to fuse a stable orientation.
// Producer and control task are deliberately left un-started by the caller so
// no commands flow and no PWM is written while we wait. OtaSafeMode must be
// initialized first so the robot stays reflashable while gated here.
//
// IMUPLUS mode: isCalibrated() = (gyro == 3 && accel == 3). Mag/sys ignored.
//
// Two paths:
//   - Warm boot (NVS hit, offsets restored): chip's cal counters lag the
//     offsets by ~10–20s but the fusion is already good. Only wait for gyro
//     to settle — sub-second on a stationary chip.
//   - Cold boot (no NVS): operator must do 6 stable accel orientations,
//     ~10s each. Total ~60s with a deliberate cube fixture.
void waitForCalibration() {
    if (g_imu.wasRestored()) {
        RemoteSerial::println("[cal] warm boot — waiting for gyro to settle.");
        while (g_imu.read().calibration.gyro < 3) {
            BringUp::tick();
            delay(CAL_POLL_PERIOD_MS);
        }
        RemoteSerial::println("[cal] gyro settled — arming teleop.");
        return;
    }

    RemoteSerial::println("[cal] cold boot — full IMUPLUS calibration required.");
    RemoteSerial::println("[cal]   gyro:  hold still");
    RemoteSerial::println("[cal]   accel: 6 distinct stable orientations, hold each ~10s");
    RemoteSerial::println("[cal]   (mag and sys are ignored in IMUPLUS — stay at 0 forever)");

    uint32_t last_print = 0;
    while (!g_imu.isCalibrated()) {
        BringUp::tick();

        // read() refreshes the calibration field and, once fully calibrated,
        // persists offsets to flash via the IMU's saved-this-boot latch.
        IMUReading r = g_imu.read();

        const uint32_t now = millis();
        if (now - last_print >= CAL_PRINT_PERIOD_MS) {
            RemoteSerial::printf("[cal] sys=%u gyro=%u accel=%u mag=%u\n",
                                 r.calibration.sys, r.calibration.gyro,
                                 r.calibration.accel, r.calibration.mag);
            last_print = now;
        }

        delay(CAL_POLL_PERIOD_MS);
    }
    RemoteSerial::println("[cal] fully calibrated — offsets saved, arming teleop.");
}

void controlTask(void* /*arg*/) {
    // Subscribe to the Task Watchdog. If this loop hangs (e.g. I2C bus
    // stretch on the IMU), TWDT panics and resets — preferable to motors
    // stuck at last PWM with no operator recovery.
    esp_task_wdt_add(NULL);

    BodyVelocity last_known{};
    uint32_t     last_fresh_ms = 0;
    bool         have_seen_fresh = false;
    ArmingState::State prev_arming = ArmingState::get();

    TickType_t lastWake = xTaskGetTickCount();
    const TickType_t period = pdMS_TO_TICKS(CONTROL_PERIOD_MS);

    UBaseType_t stack_hwm_min = static_cast<UBaseType_t>(-1);
    uint32_t    hwm_iter = 0;

    static uint32_t prev_us = 0;
    static float    dt_min = 1e9f;
    static float    dt_max = 0.0f;
    static float    dt_sum = 0.0f;
    static uint16_t dt_n   = 0;
    static uint32_t telem_seq = 0;

    while (true) {
        // 1) Pull freshest command from latch.
        auto fresh = g_latch->read();
        const uint32_t now = millis();
        if (fresh.has_value()) {
            last_known      = *fresh;
            last_fresh_ms   = now;
            have_seen_fresh = true;
        }

        // 2) Arming-edge dispatch. Runs BEFORE the staleness ramp so the
        //    Armed-edge zeroing of last_known prevents a stale-replay on the
        //    first armed tick.
        //      Disarmed->Armed: seed last_fresh_ms so the velocity ramp
        //                       starts coherent on the first armed tick,
        //                       mark have_seen_fresh, clear last_known so
        //                       the ramp can't replay a prior cycle's
        //                       command. Then controller->onArmed() clears
        //                       wheel-level + balance PID state that drifted
        //                       while update(dt) ran during Disarmed.
        //      Armed->Disarmed: onDisarmed() clears wheel-level + balance
        //                       PID state so re-arm doesn't slam wheels (B3).
        //      *->Killed:       single hard brake on entry; subsequent ticks
        //                       are no-ops (avoids re-clearing _inFault every
        //                       tick which would defeat the Schmitt gate).
        const auto arming = ArmingState::get();
        if (arming != prev_arming) {
            if (arming == ArmingState::State::Armed) {
                last_fresh_ms   = now;
                have_seen_fresh = true;
                last_known      = BodyVelocity{0.0f, 0.0f, 0.0f};
                g_controller->onArmed();
            } else if (prev_arming == ArmingState::State::Armed &&
                       arming      == ArmingState::State::Disarmed) {
                g_controller->onDisarmed();
            } else if (arming == ArmingState::State::Killed) {
                g_controller->stop();
            }
        }

        // 3) Drive command via staleness alone. The producer's connected()
        //    flag can lie on half-open TCP; age < 200ms is the actual safety
        //    net so we don't gate on connected() anymore.
        BodyVelocity drive_cmd{0.0f, 0.0f, 0.0f};
        if (have_seen_fresh) {
            const uint32_t age = now - last_fresh_ms;
            if (age < STALENESS_TIMEOUT_MS) {
                const float scale = 1.0f - static_cast<float>(age) /
                                            static_cast<float>(STALENESS_TIMEOUT_MS);
                drive_cmd = { last_known.vx * scale,
                              last_known.vy * scale,
                              last_known.omega * scale };
            }
        }

        const uint32_t now_us = micros();
        const float dt_measured = (prev_us == 0)
            ? (CONTROL_PERIOD_MS / 1000.0f)
            : (now_us - prev_us) * 1e-6f;
        prev_us = now_us;

        if (dt_n < 100) {
            if (dt_measured < dt_min) dt_min = dt_measured;
            if (dt_measured > dt_max) dt_max = dt_measured;
            dt_sum += dt_measured;
            dt_n++;
            if (dt_n == 100) {
                const float mean = dt_sum / dt_n;
                RemoteSerial::printf(
                    "[loop] dt min=%.3fms mean=%.3fms max=%.3fms jitter=%.3fms\n",
                    dt_min * 1000, mean * 1000, dt_max * 1000,
                    (dt_max - dt_min) * 1000);
                dt_min = 1e9f; dt_max = 0.0f; dt_sum = 0.0f; dt_n = 0;
            }
        }

        // 4) Arming-gated dispatch. Killed brakes immediately (edge already
        //    called stop() once); Armed runs the controller against the
        //    (possibly ramped-to-zero) drive_cmd; Disarmed hard-zeros and
        //    lets the per-wheel PIDs hold motors at zero. OTA composes by
        //    driving ArmingState::disarm() from OtaSafeMode::onStart().
        //    Short-term producer silence (>200ms) ramps drive_cmd to zero
        //    via STALENESS_TIMEOUT_MS in step 3; the controller stays armed.
        // Single per-tick IMU read shared with the gyro-quiet pre-arm
        // buffer below. Killed skips both the read and the buffer push
        // (clearkill → Disarmed is required before any arm() can succeed,
        // so the buffer warms naturally on the way back).
        const float dt = static_cast<float>(CONTROL_PERIOD_MS) / 1000.0f;
        IMUReading tick_imu{};
        bool tick_imu_valid = false;
        if (arming != ArmingState::State::Killed) {
            tick_imu = g_imu.read();
            tick_imu_valid = true;
            ArmingState::recordGyroZ(tick_imu.gyro.z);
        }

        if (arming == ArmingState::State::Killed) {
            drive_cmd = {0.0f, 0.0f, 0.0f};
        } else if (arming == ArmingState::State::Armed) {
            g_controller->update(drive_cmd, tick_imu, dt);
        } else {
            drive_cmd = {0.0f, 0.0f, 0.0f};
            g_drivetrain.drive(drive_cmd);
        }
        g_drivetrain.update(dt);

        BalanceTelemetry t{};
        if (arming == ArmingState::State::Armed) {
            t = g_controller->lastTelemetry();
        } else {
            // Read raw IMU even when disarmed — operator wants to verify
            // before arming. When Killed we don't read (Killed already
            // skipped the I2C bus above), but we still emit the gain mirror.
            if (tick_imu_valid) {
                const IMUReading& imu_reading = tick_imu;
                t.quat_w = imu_reading.orientation.w;
                t.quat_x = imu_reading.orientation.x;
                t.quat_y = imu_reading.orientation.y;
                t.quat_z = imu_reading.orientation.z;
                t.accel_x = imu_reading.linearAccel.x;
                t.accel_y = imu_reading.linearAccel.y;
                t.accel_z = imu_reading.linearAccel.z;
                t.gyro_x_raw = imu_reading.gyro.x;
                t.gyro_y_raw = imu_reading.gyro.y;
                t.gyro_z_raw = imu_reading.gyro.z;
            }
            const BalanceConfig snap = g_tuner.snapshot();
            t.pitch_Kp = snap.pitchKp; t.pitch_Ki = snap.pitchKi; t.pitch_Kd = snap.pitchKd;
            t.roll_Kp  = snap.rollKp;  t.roll_Ki  = snap.rollKi;  t.roll_Kd  = snap.rollKd;
            t.yaw_rate_Kp = snap.yawRateKp;
            t.yaw_rate_Ki = snap.yawRateKi;
            t.heading_Kp  = snap.headingKp;
            t.pitch_deadband = snap.pitchDeadband;
            t.roll_deadband  = snap.rollDeadband;
            t.max_output_velocity = snap.maxOutputVelocity;
            t.envelope_enter_sin  = snap.envelopeEnterSin;
            t.envelope_exit_sin   = snap.envelopeExitSin;
            t.gyro_pitch_sign     = snap.gyroPitchSign;
            t.gyro_roll_sign      = snap.gyroRollSign;
            t.gyro_yaw_sign       = snap.gyroYawSign;
            t.tilt_per_velocity   = snap.tiltPerVelocity;
            t.max_tilt_setpoint   = snap.maxTiltSetpoint;
        }

        t.seq = telem_seq++;
        t.t_us = now_us;
        t.dt_measured = dt_measured;
        t.dt_used     = dt;
        t.cmd_vx_raw = last_known.vx;
        t.cmd_vy_raw = last_known.vy;
        t.cmd_omega_raw = last_known.omega;
        t.cmd_vx = drive_cmd.vx;
        t.cmd_vy = drive_cmd.vy;
        t.cmd_omega = drive_cmd.omega;
        t.cmd_age_ms = have_seen_fresh ? (now - last_fresh_ms) : 0;
        t.cmd_stale  = (have_seen_fresh &&
                        (now - last_fresh_ms) >= STALENESS_TIMEOUT_MS) ? 1 : 0;
        t.armed_state = (arming == ArmingState::State::Armed)  ? 1
                      : (arming == ArmingState::State::Killed) ? 2 : 0;

        {
            const auto wt = g_drivetrain.getWheelTelemetry();
            for (int i = 0; i < 3; ++i) {
                t.wheel_target_rpm[i] = wt[i].target_rpm;
                t.wheel_meas_rpm[i]   = wt[i].meas_rpm;
                t.wheel_P[i] = wt[i].P;
                t.wheel_I[i] = wt[i].I;
                t.wheel_D[i] = wt[i].D;
                t.wheel_out[i] = wt[i].out;
            }
        }

        if (arming != prev_arming) {
            if (arming == ArmingState::State::Armed) t.event_flags |= kEvent_ARMED_EDGE;
            if (prev_arming == ArmingState::State::Armed &&
                arming      == ArmingState::State::Disarmed) {
                t.event_flags |= kEvent_DISARMED_EDGE;
            }
            if (arming == ArmingState::State::Killed) t.event_flags |= kEvent_KILLED_EDGE;
            if (prev_arming == ArmingState::State::Killed &&
                arming      != ArmingState::State::Killed) {
                t.event_flags |= kEvent_KILL_CLEARED;
            }
        }

        // Pre-arm gyro-quiet rejection (single-shot, set inside arm() when
        // the gate refused). Surfaces here so any rejected arm attempt
        // shows up on the same telemetry tick.
        if (ArmingState::consumePrearmRejected()) {
            t.event_flags |= kEvent_PREARM_REJECTED;
        }

        BalanceTelemetryWs::publish(t);

        prev_arming = arming;

        esp_task_wdt_reset();

        if (hwm_iter < 100) {
            UBaseType_t hwm = uxTaskGetStackHighWaterMark(NULL);
            if (hwm < stack_hwm_min) stack_hwm_min = hwm;
            if (++hwm_iter == 100) {
                Serial.printf("[ctrl] stack HWM min over 100 iters: %u words free\n",
                              stack_hwm_min);
            }
        }

        vTaskDelayUntil(&lastWake, period);
    }
}

}  // namespace

void setup() {
    // Network/OTA FIRST. If anything below this fails, the chip stays
    // reachable via STA (bb8-robot.local) or the always-on recovery
    // SoftAP (bb8-robot-recovery at 192.168.4.1).
    BringUp::begin();
    ArmingState::begin();
    RemoteSerial::onMessage(handleRemoteSerialLine);
    RemoteSerial::println("BB-8 main_robot starting.");
    RemoteSerial::println("[arming] boot state: Disarmed");

    Wire.begin(I2C_SDA, I2C_SCL);

    g_motor0.begin();
    g_motor1.begin();
    g_motor2.begin();

    if (!g_imu.begin()) {
        // Degraded mode: skip producer/controller/control-task creation and
        // return. loop() keeps calling OtaSafeMode::tick() so the chip stays
        // reachable for an OTA reflash that fixes the wiring or driver.
        RemoteSerial::println("[imu] init failed — entering OTA-only degraded mode.");
        return;
    }

    g_latch      = new CommandLatch<BodyVelocity>();
    g_producer   = new WebSocketCommandProducer(*g_latch, WS_PORT);

    BalanceConfig boot_cfg;
    if (!BalanceConfigStorage::load(boot_cfg)) {
        boot_cfg = RobotConstants::balanceConfig();
        RemoteSerial::println("[balance] no persisted config; using defaults");
    }
    g_tuner.begin(boot_cfg);
    BalanceHttpApi::registerRoutes(RemoteSerial::server(), g_tuner);
    ArmingHttpApi::registerRoutes(RemoteSerial::server());
    BalanceTelemetryWs::init(RemoteSerial::server());
    BalanceTelemetryHttpApi::registerRoutes(RemoteSerial::server());
    g_controller = new BalancingDrivetrainController(g_drivetrain, g_imu, g_tuner.slot());
    g_controller->setTuner(&g_tuner);

    // Gate: no producer, no control task, no PWM until the IMU is fully
    // calibrated. Motors stay at PWM=0 from begin() throughout this wait.
    // Build with -DSKIP_IMU_CAL to bypass for bench testing.
#ifndef SKIP_IMU_CAL
    waitForCalibration();
#else
    RemoteSerial::println("[cal] SKIP_IMU_CAL set — arming teleop without calibration.");
#endif

    g_producer->start();

    // Tighten the global Task Watchdog timeout. Affects IDLE tasks too, but
    // 1s is comfortably above their normal slack.
    esp_task_wdt_init(TWDT_TIMEOUT_S, true);

    xTaskCreatePinnedToCore(
        &controlTask,
        "control",
        CONTROL_TASK_STACK_BYTES,
        nullptr,
        CONTROL_TASK_PRIORITY,
        nullptr,
        CONTROL_TASK_CORE);

    RemoteSerial::println("BB-8 ready.");
}

void loop() {
    BringUp::tick();
    vTaskDelay(pdMS_TO_TICKS(LOOP_TICK_MS));
}

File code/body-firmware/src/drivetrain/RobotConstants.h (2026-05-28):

#pragma once

#include <cmath>
#include <cstdint>
#include "BalanceConfig.h"
#include "DrivetrainConfig.h"

namespace RobotConstants {

constexpr float WHEEL_RADIUS  = 0.046225f;  // 9.245 cm diameter / 2, in meters
constexpr float ROBOT_RADIUS  = 0.1745f;    // center to wheel contact, in meters
constexpr float TILT_ANGLE    = 30.0f * static_cast<float>(M_PI) / 180.0f;
constexpr float MAX_RPM       = 251.0f;

// Yaw control envelope. OMEGA_MAX bounds inner yaw-rate PID output and (in
// Commit 4) clamps the outer heading-P output before it feeds the inner loop.
// YAW_SPIN_THRESHOLD is the |gyro.z| above which the controller assumes a
// runaway spin (720 deg/s ≈ 12.566 rad/s); sustained for YAW_SPIN_TRIP_MS the
// recovery latch fires and omega is forced to 0 until rate drops back below.
constexpr float    OMEGA_MAX             = 3.5f;     // rad/s (~200 dps)
constexpr float    YAW_SPIN_THRESHOLD    = 12.566f;  // rad/s (~720 dps)
constexpr uint32_t YAW_SPIN_TRIP_MS      = 100;

// Teleop control-loop timing.
constexpr uint32_t STALENESS_TIMEOUT_MS = 200;   // ramp-to-zero window on silence
constexpr uint32_t CONTROL_PERIOD_MS    = 10;    // 100 Hz tick

inline DrivetrainConfig drivetrainConfig() {
    constexpr float DEG = static_cast<float>(M_PI) / 180.0f;
    return {
        .wheelRadius = WHEEL_RADIUS,
        .robotRadius = ROBOT_RADIUS,
        .tiltAngle   = TILT_ANGLE,
        .maxRPM      = MAX_RPM,
        // Pull config: motor 0 at back (180°), motors 1 & 2 at front-right (300°)
        // and front-left (60°). Drive wheels load up under forward acceleration.
        .wheelAngles = {180.0f * DEG, 300.0f * DEG, 60.0f * DEG},
    };
}

inline BalanceConfig balanceConfig() {
    return {
        .tiltPerVelocity   = 0.30f,   // 1 m/s → ~17° tilt
        .maxTiltSetpoint   = 0.35f,   // ~20°; leaves ample headroom below 60° fault envelope
        .pitchKp = 1.50f, .pitchKi = 0.0f, .pitchKd = 0.15f,
        .rollKp  = 1.50f, .rollKi  = 0.0f, .rollKd  = 0.15f,
        .pitchDeadband     = 0.0f,    // rad; off by default, raise to kill limit cycle at rest
        .rollDeadband      = 0.0f,
        .maxOutputVelocity = 1.00f,   // m/s; just below physical max (~1.05)
        .envelopeEnterSin  = 0.866f,  // sin(60°)
        .envelopeExitSin   = 0.819f,  // sin(55°)
        .gyroPitchSign     = 1.0f,
        .gyroRollSign      = 1.0f,
        .yawRateKp = 0.0f, .yawRateKi = 0.0f,
        // Conservative starter for heading hold. Engaged by default at arm
        // time; expect to tune at the bench. Zero would keep heading hold
        // ON in shape but emit zero rate command — set non-zero so the
        // default-flashed firmware actually holds heading.
        .headingKp         = 1.0f,
        .gyroYawSign       = 1.0f,
    };
}

}

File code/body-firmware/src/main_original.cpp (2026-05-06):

/*
 * BB-8 Body Firmware — Motor Spin Test
 * Serial input: "<motor> <speed>" e.g. "0 0.5" or "1 -1.0"
 * "stop" to brake all motors
 */

#include <Arduino.h>
#include "pins.h"
#include "L298NDriver.h"

static constexpr int NUM_MOTORS = 3;

L298NDriver drivers[NUM_MOTORS] = {
    L298NDriver(MOTOR0_PINS),
    L298NDriver(MOTOR1_PINS),
    L298NDriver(MOTOR2_PINS),
};

void setup() {
    Serial.begin(115200);
    for (int i = 0; i < NUM_MOTORS; i++) {
        drivers[i].begin();
    }
    Serial.println("Motor test ready. Send: <motor 0-2> <speed -1.0 to 1.0>");
    Serial.println("Send 'stop' to brake all.");
}

void loop() {
    if (!Serial.available()) return;

    String line = Serial.readStringUntil('\n');
    line.trim();

    if (line == "stop") {
        for (int i = 0; i < NUM_MOTORS; i++) {
            drivers[i].brake();
        }
        Serial.println("All motors braked.");
        return;
    }

    int motor = line.substring(0, line.indexOf(' ')).toInt();
    float speed = line.substring(line.indexOf(' ') + 1).toFloat();

    if (motor < 0 || motor >= NUM_MOTORS) {
        Serial.println("ERR: motor must be 0-2");
        return;
    }
    if (speed < -1.0f || speed > 1.0f) {
        Serial.println("ERR: speed must be -1.0 to 1.0");
        return;
    }

    drivers[motor].setOutput(speed);
    Serial.printf("Motor %d -> %.2f\n", motor, speed);
}

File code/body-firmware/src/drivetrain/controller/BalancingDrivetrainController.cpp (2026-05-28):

/*
 * BB-8 Body Firmware — MIT 2026 SP, Team Sphere
 */

#include "BalancingDrivetrainController.h"

#include <cmath>
#include <limits>

#include "BalanceTuner.h"
#include "RobotConstants.h"
#include "quatToBodyGravity.h"

namespace {

inline float clampf(float v, float lo, float hi) {
    if (v < lo) return lo;
    if (v > hi) return hi;
    return v;
}

// Stick-deadband threshold for heading-hold engagement (rad/s). Operator
// commands below this magnitude trip the outer P loop into hold mode; above,
// it passes through as a rate command.
constexpr float HEADING_DEADBAND = 0.05f;

// Low-pass time constant on the rate-setpoint that feeds the inner yaw PID.
// Prevents a snap on stick release that would otherwise hand the inner loop
// an instantaneous setpoint step from cmd.omega → outer-P output.
constexpr float LP_TAU = 0.15f;

}  // namespace

BalancingDrivetrainController::BalancingDrivetrainController(
    Drivetrain<BodyVelocity>& drive,
    IMU<IMUReading>& imu,
    std::atomic<const BalanceConfig*>& configSlot)
    : DrivetrainController<BodyVelocity, IMUReading, BodyVelocity>(drive, imu),
      _pitchPid(configSlot.load(std::memory_order_acquire)->pitchKp,
                configSlot.load(std::memory_order_acquire)->pitchKi,
                configSlot.load(std::memory_order_acquire)->pitchKd,
                -configSlot.load(std::memory_order_acquire)->maxOutputVelocity,
                +configSlot.load(std::memory_order_acquire)->maxOutputVelocity),
      _rollPid(configSlot.load(std::memory_order_acquire)->rollKp,
               configSlot.load(std::memory_order_acquire)->rollKi,
               configSlot.load(std::memory_order_acquire)->rollKd,
               -configSlot.load(std::memory_order_acquire)->maxOutputVelocity,
               +configSlot.load(std::memory_order_acquire)->maxOutputVelocity),
      _yawRatePid(0.0f, 0.0f, 0.0f, -RobotConstants::OMEGA_MAX, +RobotConstants::OMEGA_MAX),
      _configSlot(configSlot) {}

void BalancingDrivetrainController::update(const BodyVelocity& cmd,
                                           const IMUReading& imuData,
                                           float dt) {
    const BalanceConfig& cfg = *_configSlot.load(std::memory_order_acquire);

    // Top-of-update IMU validity guard. A NaN quaternion or any gyro axis
    // would poison every downstream math op (quatToBodyGravity → tilt → PID),
    // and the PID's BB8_ASSERT(isfinite(rate)) would abort. Gyro x/y are
    // explicit rate inputs to the pitch/roll PIDs; gyro.z feeds the yaw
    // loop. Skipping the drivetrain write is safer than driving on garbage;
    // persistent NaNs surface as a continuous kEvent_IMU_INVALID in telemetry.
    const Quat& q = imuData.orientation;
    if (!std::isfinite(q.w) || !std::isfinite(q.x) || !std::isfinite(q.y) ||
        !std::isfinite(q.z) || !std::isfinite(imuData.gyro.x) ||
        !std::isfinite(imuData.gyro.y) || !std::isfinite(imuData.gyro.z)) {
        _lastTelemetry = BalanceTelemetry{};
        _lastTelemetry.dt_used     = dt;
        _lastTelemetry.event_flags = kEvent_IMU_INVALID;
        _lastTelemetry.in_fault    = _inFault ? 1 : 0;
        return;
    }

    // Push live-tuned gains into the PIDs every tick. setGains is a 3-float
    // mutation; cost is negligible vs. allowing tuner edits to take effect.
    _pitchPid.setGains(cfg.pitchKp, cfg.pitchKi, cfg.pitchKd);
    _rollPid.setGains(cfg.rollKp, cfg.rollKi, cfg.rollKd);
    _yawRatePid.setGains(cfg.yawRateKp, cfg.yawRateKi, 0.0f);
    _pitchPid.setDeadband(cfg.pitchDeadband);
    _rollPid.setDeadband(cfg.rollDeadband);

    // Telemetry is rebuilt every tick. Fields untouched here (wheel_*, seq,
    // t_us, dt_measured, cmd_age_ms, armed_state, cmd_stale) are owned by the
    // control task and overwritten before publishing.
    _lastTelemetry = BalanceTelemetry{};
    _lastTelemetry.dt_used = dt;
    _lastTelemetry.cmd_vx        = cmd.vx;
    _lastTelemetry.cmd_vy        = cmd.vy;
    _lastTelemetry.cmd_omega     = cmd.omega;
    _lastTelemetry.cmd_vx_raw    = cmd.vx;
    _lastTelemetry.cmd_vy_raw    = cmd.vy;
    _lastTelemetry.cmd_omega_raw = cmd.omega;
    _lastTelemetry.quat_w    = imuData.orientation.w;
    _lastTelemetry.quat_x    = imuData.orientation.x;
    _lastTelemetry.quat_y    = imuData.orientation.y;
    _lastTelemetry.quat_z    = imuData.orientation.z;
    // gravity-removed; raw accel would duplicate info in the quaternion.
    _lastTelemetry.accel_x   = imuData.linearAccel.x;
    _lastTelemetry.accel_y   = imuData.linearAccel.y;
    _lastTelemetry.accel_z   = imuData.linearAccel.z;
    _lastTelemetry.gyro_x_raw = imuData.gyro.x;
    _lastTelemetry.gyro_y_raw = imuData.gyro.y;
    _lastTelemetry.gyro_z_raw = imuData.gyro.z;
    _lastTelemetry.pitch_Kp = cfg.pitchKp;
    _lastTelemetry.pitch_Ki = cfg.pitchKi;
    _lastTelemetry.pitch_Kd = cfg.pitchKd;
    _lastTelemetry.roll_Kp  = cfg.rollKp;
    _lastTelemetry.roll_Ki  = cfg.rollKi;
    _lastTelemetry.roll_Kd  = cfg.rollKd;
    _lastTelemetry.yaw_rate_Kp = cfg.yawRateKp;
    _lastTelemetry.yaw_rate_Ki = cfg.yawRateKi;
    _lastTelemetry.heading_Kp  = cfg.headingKp;
    _lastTelemetry.pitch_deadband      = cfg.pitchDeadband;
    _lastTelemetry.roll_deadband       = cfg.rollDeadband;
    _lastTelemetry.max_output_velocity = cfg.maxOutputVelocity;
    _lastTelemetry.envelope_enter_sin  = cfg.envelopeEnterSin;
    _lastTelemetry.envelope_exit_sin   = cfg.envelopeExitSin;
    _lastTelemetry.gyro_pitch_sign     = cfg.gyroPitchSign;
    _lastTelemetry.gyro_roll_sign      = cfg.gyroRollSign;
    _lastTelemetry.gyro_yaw_sign       = cfg.gyroYawSign;
    _lastTelemetry.tilt_per_velocity   = cfg.tiltPerVelocity;
    _lastTelemetry.max_tilt_setpoint   = cfg.maxTiltSetpoint;

    float gx, gy, gz;
    quatToBodyGravity(imuData.orientation, gx, gy, gz);
    float tiltMagSin = std::sqrt(gx * gx + gy * gy);
    _lastTelemetry.gx = gx;
    _lastTelemetry.gy = gy;
    _lastTelemetry.gz = gz;
    _lastTelemetry.tilt_mag_sin = tiltMagSin;

    // Sign-flipped yaw rate is needed both for the inner PID below and for
    // the heading integrator. Compute it once, here, before the fault gate
    // — the heading integrator must keep advancing during tilt-faults so
    // that on fault exit the held heading still reflects truth.
    const float gyro_yaw_rate = cfg.gyroYawSign * imuData.gyro.z;
    _headingIntegrator += gyro_yaw_rate * dt;
    _lastTelemetry.gyro_yaw_rate    = gyro_yaw_rate;
    _lastTelemetry.heading_integrated = _headingIntegrator;
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

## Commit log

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2026-04-23 fix: move CI workflow to repo root, add path filter and push trigger
    GitHub only reads .github/workflows/ at the repo root. Also adds push
    trigger on main and path filter so CI only runs on code/ changes.
2026-04-23 fix: refactor VideoSource to pass callbacks via connect() instead of mutable props
    Mutable callback properties on VideoSource objects violated React
    Compiler's immutability rules, breaking lint. Callbacks are now passed
    as a second argument to connect().
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2026-05-06 chore: fix a few bugs
    [BNO055IMU.h]
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2026-05-06 feat: add MovingAverage utility with unit tests
    Header-only template class for computing a running average over a
    fixed-size window. Reusable for RPM smoothing, IMU filtering, and
    PID derivative smoothing.
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2026-05-06 fix: re-enable H-bridge after coast/brake, add FFF and testable asserts
    BTS7960Driver bug: setOutput() after coast (Disable) or brake (Stop)
    would silently fail because Enable() was never called again. Fixed by
    calling Enable() before TurnLeft/TurnRight.
    Also adds FFF (Fake Function Framework) for native tests, upgrades
    BTS7960 stub with FFF DECLARE fakes, and makes BB8_ASSERT_HANDLER
    overridable so tests can verify assertion behavior.
    [BTS7960Driver.cpp]
2026-05-06 test: add 26 edge case tests across motor stack
    BTS7960Driver (11 tests): enable/disable lifecycle, coast vs brake,
    recover after coast/brake, direction switching, dead zone, assert
    boundaries.
    FIT0186Motor (8 new): reverse direction, micros overflow, dt=0 skip
    with tick preservation, zero CPR, filter convergence on reversal,
    split interval consistency, high RPM.
    MovingAverage (7 new): window size 1, push after reset, negative
    values, mixed signs, partial fill, NaN propagation, accuracy after
    1000 pushes.
2026-05-06 fix: correct PWM range to uint8_t 0-255, add dead zone, gear ratio RPM, zero CPR assert, pin sentinels
    - BTS7960 real library uses uint8_t 0-255, not int8_t 0-127
    - Dead zone: Disable() instead of TurnLeft(0) for near-zero PWM
    - RPM now reports output-shaft speed (divided by GEAR_RATIO)
    - BB8_ASSERT on zero encoderCPR in FIT0186Motor constructor
    - Placeholder pins use 0xFF sentinel instead of GPIO 0
    [BTS7960Driver.cpp]
2026-05-06 fix: use separate EN and PWM pins for proper full H-bridge drive
    BTS7960 library needs 4 independent pins (L_EN, R_EN, L_PWM, R_PWM).
    Tying EN to PWM caused TurnLeft/TurnRight to disable the opposite
    half-bridge instead of setting its PWM to 0, resulting in half-bridge
    drive with a floating motor terminal.
    [BTS7960Driver.cpp]
2026-05-06 feat: add L298N driver, serial motor test harness, and test procedure
    Replace BTS7960 driver with L298N (EN jumpered, PWM on fwd/rev pins).
    Serial interface accepts "<motor> <speed>" commands for manual testing.
    [L298NDriver.cpp]
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2026-05-06 fix: use analogWrite consistently to avoid ESP32 PWM channel leak
    digitalWrite does not detach LEDC PWM channels on ESP32, so pins
    keep outputting the last PWM value. Use analogWrite(pin, 0) instead.
    Also swap motor 0 pins to match actual wiring (IN3=14, IN4=27).
    [L298NDriver.cpp]
2026-05-07 feat: add omni-drivetrain IK derivation
    Body-frame (x-forward, y-right, z-down) 3-omniwheel inverse
    kinematics with tilt correction for spherical shell geometry.
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2026-05-07 feat: add OmniKinematics with tests
    Stateless IK for 3 omniwheels at 120-deg spacing with tilt
    correction and proportional saturation scaling.
    [OmniKinematics.h]
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2026-05-07 fix: correct IK sign error, harden PID, clean up drivetrain interface
    Negate sin(θ) coefficient in IK formula — the projection onto the
    wheel rolling direction t = (-sinθ, cosθ) requires -sin(θ)*vx, not
    +sin(θ)*vx. The original sign caused forward commands to produce
    backward motion.
    Also: guard PID derivative against dt≈0, initialize lastLoopTime in
    test harness setup(), push dt into Drivetrain base class virtual
    interface, and remove dead code.
    [OmniDrivetrain.h, OmniKinematics.h]
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2026-05-07 fix encoder CPR for full-quad decoding and add measured robot constants
    CPR 700→2800 to account for 4x edge counting in attachFullQuad,
    remove redundant gear ratio division in RPM calc.
    Add RobotConstants.h with measured wheel/robot radius and tilt angle.
    [RobotConstants.h]
2026-05-07 fix motor driver and encoder pin assignments for correct direction
    Swap motors 1&2 driver pins and all encoder A/B pins so positive
    PID output produces positive encoder RPM on all three motors.
2026-05-07 add drivetrain test firmware with PID deadband and RPM display
    Add PID deadband to suppress jitter at zero target.
    Add drivetrain_test and motor_test PlatformIO environments.
    Rewrite main_drivetrain_test with tuned PID gains, real robot
    constants, and target-vs-actual RPM serial display.
    [OmniDrivetrain.h]
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2026-05-08 fix broken BNO055 stub, L298N driver, and FIT0186 motor tests
    Add class-scoped vector type constants to BNO055 stub so
    Adafruit_BNO055::VECTOR_EULER resolves. Rewrite L298N test for
    current fwd/rev API. Remove stale gear ratio division from FIT0186
    test to match current motor code.
2026-05-08 add encoder RPM display to motor test and kill motor pins in IMU main
    Motor test now uses FIT0186Motor with encoder feedback; 'rpm' command
    toggles live RPM output. IMU main drives all motor GPIOs LOW on boot
    to prevent floating pins from spinning motors.
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2026-05-08 add MockCommandProducer fixture and PassthroughDrivetrainController stub
    MockCommandProducer<T> is a synchronous test fixture that injects values
    into a CommandLatch<T> when started; useful for wiring-layer tests once a
    real DrivetrainController exists.
    PassthroughDrivetrainController is the v1 stub: update(cmd, imu) forwards
    cmd straight to the drivetrain (IMU reading reserved for future yaw-lock).
    stop() calls drivetrain.stop(). Tests use the existing test_mock_motor.h
    pattern to verify forwarding and stop semantics.
2026-05-08 add WebSocketCommandProducer
    Hosts an arduinoWebSockets server (default port 81) on Core 0 in a
    dedicated FreeRTOS task. Parses CSV text frames 'vx,vy,omega' into
    BodyVelocity and writes to the latch. connected() reflects WS connect/
    disconnect events for fast transport-death detection by the consumer.
    stop() is synchronous: signals the task to exit and waits on a binary
    semaphore (1s timeout fallback) so callers can rely on resources being
    released on return. Parse failures are silently dropped but logged via
    Serial at 1 Hz to aid bench debugging.
    [WebSocketCommandProducer.cpp]
2026-05-08 wire end-to-end teleop in main_robot.cpp and add [env:robot]
    main_robot.cpp brings up motors, BNO055 IMU, WiFi STA, and the
    WebSocketCommandProducer, then pins a 100Hz control task to Core 1.
    The control task implements the dead-window safety policy:
    - producer.connected() == false -> drive {0,0,0}
    - fresh frame seen, age < 200ms -> drive last_known * (1 - age/200ms)
    (linear ramp toward zero)
    - past 200ms staleness threshold -> drive {0,0,0}
    A have_seen_fresh flag prevents the boot window (last_fresh_ms = 0,
    millis() < 200) from being classified as fresh.
    [env:robot] extends env:wemos_d1_uno32 and adds links2004/WebSockets and
    ESP32Encoder to lib_deps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
    [main_robot.cpp]
2026-05-08 harden teleop pipeline: refactor structure, control loop safety, ws robustness
    Architecture
    - Move CommandLatch from input/ to util/sync/ (generic SPSC primitive)
    - Extract Lifecycle interface so polled producers can skip start/stop
    - Move STALENESS_TIMEOUT_MS / CONTROL_PERIOD_MS to RobotConstants
    Composition root
    - Globals (latch, producer, controller) constructed in setup() instead of
    static-init, so FreeRTOS objects are created in a known runtime context
    Control loop
    - Drop redundant connected() gate; staleness alone (200ms) gates motion
    since connected() can lie on half-open TCP
    - Control task stack 4096 -> 8192 with high-water-mark instrumentation
    - Subscribe control task to TWDT,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
    [RobotConstants.h, WebSocketCommandProducer.cpp, main_robot.cpp]
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2026-05-08 remap motor and IMU pins to match new harness
    - Motor 1: fwd 17 <-> rev 16 swap
    - Motor 2: fwd/rev 19/18 -> 25/26
    - IMU I2C: SDA 26 -> 21, SCL 25 -> 22 (in both main_robot and main_imu)
    [main_robot.cpp]
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2026-05-12 parameterize wheel azimuths via DrivetrainConfig::wheelAngles
    Replace the three hardcoded sin/cos pairs in OmniKinematics with a
    config-driven array. Constructor precomputes sin/cos once. Default
    config (push, {0°, 120°, 240°}) is unchanged.
    [OmniKinematics.h, RobotConstants.h]
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2026-05-12 switch default omni layout to pull (motor 0 at back)
    Production drivetrainConfig() now uses wheelAngles {180°, 300°, 60°}:
    motor 0 idle for pure forward, motors 1 & 2 at front-right and front-left
    do all forward thrust. Under forward acceleration the pendulum platform
    loads the front wheels, so the drive wheels gain traction instead of
    slipping (cost: reverse accel is now the weak case).
    Rename the push-layout test fixture defaultConfig() to pushConfig() to
    match the new explicit pull/push naming.
    [RobotConstants.h]
2026-05-12 pin partition table to default.csv
    Make the OTA-capable dual-app partition layout explicit so a future
    PlatformIO/Arduino-ESP32 update can't silently swap in a single-app layout
    and break OTA writes. This is a no-op on the current toolchain (default.csv
    is already the wemos_d1_uno32 default) but locks the layout going forward.
2026-05-12 source OTA_PASSWORD from env var with build-time length check
    OTA_PASSWORD is now injected at build time via -DOTA_PASSWORD='"${sysenv.OTA_PASSWORD}"',
    so the same env var defines both the firmware-embedded password (used by
    ArduinoOTA.setPassword) and the upload tool's --auth value. Build value and
    upload value cannot drift because they're the same variable.
    A static_assert in src/network/ota_password_check.cpp fails the build if
    OTA_PASSWORD is unset (sizeof("") == 1) or shorter than 8 chars, the WPA2
    PSK minimum we'll need once the recovery SoftAP uses it as the AP password.
    OTA_PASSWORD removed from wifi_credentials.h / .example.h; the example
    header now documents the env-var workflow.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
2026-05-12 add OtaSafeMode module shared by every main, with link-time enforcement
    Single shared bring-up of WiFi STA + always-on recovery SoftAP +
    ArduinoOTA, plus a mark-valid rollback timer and AP-aware reboot
    watchdog. Each main_*.cpp places OTA_SAFE_MODE_FOR("name") at file
    scope; the macro defines OtaSafeMode::kMainName, which the .cpp
    references from an __attribute__((constructor)) anchor. A main missing
    the macro fails to link with:
    undefined reference to `OtaSafeMode::kMainName'
    The constructor anchor lands in .init_array so the linker cannot drop
    the reference even mid-refactor when no one calls begin()/tick() yet.
    OTA_PASSWORD's static_assert moves here from the temporary
    ota_password_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
    [OtaSafeMode.cpp, main_robot.cpp]
2026-05-12 swap main_robot.cpp to OtaSafeMode shared module
    Replace inline WiFi/ArduinoOTA bring-up with a single OtaSafeMode::begin()
    call positioned BEFORE peripheral init, so a later IMU/I2C failure still
    leaves the chip reachable for reflash. loop() collapses to a single
    OtaSafeMode::tick() (plus the 10 Hz delay).
    Deleted: onWifiEvent(), initOta(), connectWifi(), the OTA_HOSTNAME +
    WIFI_TIMEOUT_MS + WIFI_OFFLINE_REBOOT_MS constants, and the
    g_lastWifiConnectedMs/WiFi-watchdog logic — all now owned by OtaSafeMode.
    controlTask gains a per-iteration check of OtaSafeMode::isUpdating()
    that hard-zeros drive_cmd while flash is being overwritten. This
    replaces the old ArduinoOTA.onStart hook that live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
    [main_robot.cpp]
2026-05-12 IMU failure becomes OTA-only degraded mode instead of restart
    A boot-time BNO055 init failure used to ESP.restart(), which on a
    hardware fault meant an infinite reboot loop with no recovery channel.
    Now we log, skip creating the producer/controller/control-task, and
    return from setup() — loop() keeps calling OtaSafeMode::tick() so the
    chip is reachable via STA mDNS or the always-on recovery SoftAP, and a
    fixed image can be OTA-flashed without touching USB.
    [main_robot.cpp]
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2026-05-12 add millis() wraparound tests for OtaPolicy
    Two regression tests pin the unsigned-subtraction contract so a future
    'fix' that signs the elapsed-time math can't silently brick recovery
    once millis() wraps at ~49.7 days. Raised by review pass.
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2026-05-13 kinematics: flip sign of vy and omega terms in toWheelRPMs
    The previous formula was -sin·vx - cos·vy - R·ω. With our convention
    (+vy = strafe left, +ω = CCW from above), the cos and R terms had the
    wrong sign — pure strafe and pure rotation produced inverted wheel
    commands. Tests updated to match.
    [OmniKinematics.h]
2026-05-13 pins: remap motor 2 to GPIO 13/12 and swap motor 0 encoder A/B
    Motor 2 moves off 25/26 to 13/12 to free up DAC pins for other uses.
    Motor 0's encoder A/B pins were physically swapped during wiring, so
    swap them in firmware to restore correct count direction.
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2026-05-13 drivetrain_test: route prints through RemoteSerial, add OTA env, zero PWM on update
    Mirrors what motor_test already does — WebSerial-backed RemoteSerial
    for over-the-air telemetry plus an espota upload env. setup() now
    explicitly setSpeed(0) after begin() so stale LEDC state from before
    a soft-reset can't leak into the wheels, and loop() hard-zeros PWM
    while OtaSafeMode::isUpdating() so flashing can't leave wheels
    chewing on a stale target through the upload window.
2026-05-13 robot: route prints through RemoteSerial, add SKIP_IMU_CAL bench flag
    All Serial.print* in setup, calibration, and loop go through
    RemoteSerial so logs are visible over OTA. Also wires
    RemoteSerial::tick() into both the calibration wait loop and the
    main loop. New -DSKIP_IMU_CAL build flag bypasses the calibration
    gate for bench testing without the IMU bring-up dance.
    [main_robot.cpp]
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2026-05-13 firmware/ota: disable WiFi modem-sleep + atomic g_last_sta_connected_ms
    WIFI_PS_MIN_MODEM (Arduino-ESP32 3.1+ default) introduces up to ~300 ms
    downlink jitter at the AP's DTIM interval, which overruns the teleop
    WebSocket PONG deadline on flaky consumer APs. Force WIFI_PS_NONE in
    tryConnectSta and re-apply on every ARDUINO_EVENT_WIFI_STA_CONNECTED
    because the kernel resets PS on reassociation.
    Promote g_last_sta_connected_ms from `volatile uint32_t` to
    `std::atomic<uint32_t>` to match the sibling g_updating in the same TU
    and remove the cross-core tearing risk between the WiFi event task
    (writer) and the loop() task (reader).
    [OtaSafeMode.cpp]
2026-05-13 firmware/teleop: loosen WS heartbeat and switch to drop-oldest policy
    Two changes to the single-client WebSocket policy on the chip:
    - enableHeartbeat(2000, 1000, 2) -> (3000, 2500, 2). Eviction window
    goes from ~5 s to ~7.5 s so a single RTT spike on consumer Wi-Fi
    doesn't false-positive a dead client. pingInterval > pongTimeout is
    preserved (arduinoWebSockets issue #769).
    - WStype_CONNECTED now pre-empts the prior active client via
    _activeClient.exchange() and disconnects the previous holder, instead
    of rejecting the new client. This breaks the rejection loop that
    happened when the browser noticed disconnect before the chip's
    heartbeat had evicted the stale slot.
    [WebSocketCommandProducer.cpp]
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2026-05-13 safety,main_robot: fixup multi-task writer comment + auto-disarm drive call
    [main_robot.cpp]
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2026-05-13 main_robot: swap to BalancingDrivetrainController
    [main_robot.cpp]
2026-05-19 firmware: edge-aware arming FSM, PID reset on disarm, TOCTOU fix, c:armstate? verb
    - controlTask: edge-detect ArmingState transitions; on Armed→Disarmed
    reset balance PID integrators so re-arm does not slam wheels (B3);
    on Armed-edge seed last_fresh_ms so STALE_DISARM_MS backstop fires
    even when no velocity frame was sent (B4); drop have_seen_fresh
    guard from backstop check now that the seed makes it correct;
    call controller->stop() once on Killed-edge instead of per-tick.
    - BalancingDrivetrainController: add resetIntegrators() — narrower
    than stop(), preserves _inFault and drivetrain state.
    - ArmingState: arm()/disarm()/clearKill() use compare_exchange_strong
    against expec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
    [BalancingDrivetrainController.cpp, WebSocketCommandProducer.cpp, main_robot.cpp]
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2026-05-19 kinematics: fix +vx sign convention (B7)
    vx coefficient was -sin(θᵢ); REP-103 says +sin(θᵢ). Bench Phase C confirmed
    +vx rolled the shell backward under the old convention. vy and omega were
    already correct.
    [OmniKinematics.h]
2026-05-19 drivetrain: add resetPids() inner-loop hook
    Pure state-clear that zeroes per-wheel PIDs and target RPMs without braking
    the motors — distinct from stop(). Default no-op on the Drivetrain base
    so drivetrains without inner loops compile unchanged.
    [OmniDrivetrain.h]
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2026-05-19 drivetrain-controller: balancing controller — B1 output negation, deadband wire-up, arming-edge hooks
    - B1 sphere convention: negate vx_out/vy_out at the drivetrain boundary so
    positive PID gains stay physically intuitive (push back against tilt).
    The old code happened to work because the prior kinematics vx sign error
    cancelled this implicit negation.
    - Push BalanceConfig.{pitch,roll}Deadband into the PIDs each tick.
    - onArmed/onDisarmed clear wheel-level + balance PID state so the first
    armed tick computes cleanly and re-arm can't slam wheels from leftover
    Disarmed-period accumulators.
    [BalancingDrivetrainController.cpp]
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2026-05-19 network: RemoteSerial — server() accessor, WebSerial flush pump, null-strip, pre-begin safety
    - Expose internal AsyncWebServer (port 81) via server() so HTTP route
    modules can attach alongside WebSerial.
    - tick() now calls WebSerial.loop() each main-loop pass; without it WS2.x
    batches writes in a two-tier buffer and operators see one-message lag.
    - Pair with -DWSL_GLOBAL_FLUSH_TIME_MS=50 in platformio.ini for ~150ms
    worst-case end-to-end interactive latency.
    - Strip trailing 0x00 / CR / LF on inbound messages — some WebSerial
    clients append a null and Arduino String::trim() doesn't remove it,
    which broke equality dispatch in the tuner.
    - Guard print/println/printf against pre-b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
    [OtaSafeMode.cpp, RemoteSerial.cpp]
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2026-05-19 main: drop STALE_DISARM backstop, route arming edges through onArmed/onDisarmed, IMUPLUS cal split, wire HTTP routes
    - Remove the producer-silence auto-disarm (STALE_DISARM_MS): the
    short-term staleness ramp (STALENESS_TIMEOUT_MS) already zeroes the
    drive command; long-term auto-disarm was duplicating responsibility
    the operator/kill-switch should own. Backstop required a second
    WebSerial tab to verify, which made the bench protocol fragile.
    - Replace direct resetIntegrators() at the Armed→Disarmed edge with
    controller->onDisarmed(); add controller->onArmed() on Disarmed→Armed
    so wheel-level PIDs clear before the first armed tick. Mirrors the
    same dispatch in main_balance_t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
    [RobotConstants.h, main_robot.cpp]
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2026-05-19 feat(main_robot): dt jitter + telemetry publish + setup wiring
    Mirrors main_balance_test.cpp (f9ef867): per-tick dt_measured with 1 Hz
    min/mean/max/jitter print, build BalanceTelemetry from controller (Armed)
    or raw IMU + tuner snapshot (Disarmed), populate wheel telemetry + arming
    edges, publish on every tick. setup() now also wires BalanceTelemetryWs,
    BalanceTelemetryHttpApi, and the tuner pending-events consumer. Linkable
    because the WS ring and HttpApi snapshot buffers are now heap-backed.
    [main_robot.cpp]
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2026-05-19 feat(telemetry): wire gyro_pitch_sign / gyro_roll_sign through pipeline
    Adds the two sign fields to BalanceTelemetry in canonical CSV column order
    (after envelope_exit_sin, before tilt_per_velocity), populates them from
    BalanceConfig in the controller and in both mains' Disarmed/Killed branches,
    and replaces the literal 0,0 placeholders in the WS CSV emitter and HTTP JSON
    snapshot with the live values. Schema type changed to float to match storage.
    [BalanceTelemetry.h, BalancingDrivetrainController.cpp, main_robot.cpp]
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2026-05-27 feat(yaw): close inner gyro-Z rate PID
    Adds the inner rate-tracking PID for yaw. cmd.omega becomes a
    setpoint (was passthrough); measurement is cfg.gyroYawSign *
    imuData.gyro.z. Default yawRateKp=0 keeps behavior identical to
    prior commits.
    Adds two safety nets: top-of-update NaN guard on IMU data
    (skips drivetrain write, fires kEvent_IMU_INVALID), and
    yaw-spin recovery that forces omega to 0 and resets the PID
    when |gyro.z| > 720 dps sustained >100 ms.
    Heading hold remains disabled (outer loop lands in next commit).
    [BalancingDrivetrainController.cpp, RobotConstants.h]
2026-05-27 chore(controller): drop yawRateKd; extend NaN guard to gyro.x/y
    Removes yawRateKd from BalanceConfig and all downstream surfaces:
    the inner yaw rate loop is PI-only (D-term would numerically
    differentiate the gyro signal). Bumps NVS VERSION (3->4) since
    the struct layout shrinks. Column count drops 100->99.
    Extends the NaN guard at the top of update() to cover gyro.x
    and gyro.y, which feed pitch/roll PIDs as explicit rate inputs.
    Without this, a NaN in either axis would trip BB8_ASSERT inside
    the PID and abort the firmware -- exactly the failure mode the
    guard was meant to prevent.
    Two small fixes folded in: a stale comment about the yaw-spin
    'OTHER direction' window (single-accumulator im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
    [BalanceTelemetry.h, BalancingDrivetrainController.cpp]
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2026-05-27 chore(safety): loud-sentinel pre-arm buffer; extract heading reset helper
    Initializes the pre-arm gyro-quiet buffer to a "loud" sentinel
    (>threshold) at begin() and on clearKill(). Previously the buffer
    was zero-init, which let an arm attempt in the first 500 ms (or
    immediately after clearKill) succeed without any real gyro samples
    to validate. Now an arm is rejected until enough real quiet samples
    have replaced the sentinels -- self-healing in both cases.
    Folds in: _resetHeadingState() helper to consolidate the duplicated
    reset block; doc comment on kEvent_HEADING_LATCHED clarifying it does
    not fire on onArmed(); cleanup of confusing dead code in the LP-filter
    test.
    [BalanceTelemetry.h, BalancingDrivetrainController.cpp]
2026-05-27 chore(telemetry): populate heading/omega_target fields on fault, passthrough, yaw-spin
    The in-fault early-return branch and the passthrough/yaw-spin
    control branches zeroed _lastTelemetry at update() start but
    only repopulated a subset of fields before exiting. This made
    heading_setpoint, heading_err, heading_P, and omega_target_*
    read as zero/NaN during fault even though the underlying state
    was preserved -- a hidden-state bug for bench operators trying
    to diagnose whether heading hold survived a tilt event.
    Mirrors the same telemetry writes onto all three branches so
    the operator can read the current cascade state from a single
    telemetry row regardless of which branch executed.
    Runbook a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
    [BalancingDrivetrainController.cpp]
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2026-05-27 fix: change to the good file in sphere to head contact
    [Ball Transfer Unit (Plate).step, Ball Transfer Unit (Support).step]
